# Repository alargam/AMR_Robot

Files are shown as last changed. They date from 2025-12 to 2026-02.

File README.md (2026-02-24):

# 🤖 Autonomous Mobile Robot (AMR)
### ROS 2 Jazzy | Real-Time Perception | Embedded Control | Edge AI

An end-to-end **Autonomous Mobile Robot (AMR)** platform developed as a Mechatronics Engineering Graduation Project (2026).

This project integrates real-time perception, sensor fusion, embedded motor control, SLAM, and autonomous navigation into a complete robotic system designed using ROS 2 Jazzy best practices.

---

You can visit the official project website for more details: [https://delivero.site/](https://delivero.site/)

---

## 🎥 Demonstration

Mapping Demo: [link](https://www.youtube.com/shorts/1S7ldnf2kuI)

Autonomous Navigation Demo: [link](https://youtu.be/pdu4tVg_QxQ?si=NQ7DHxntDtQeoHpF)

Real-World Robot Demo [link](https://www.youtube.com/shorts/1S7ldnf2kuI)

---

# 🏗️ System Architecture

| Sensor / Input | Processing Node / Algorithm | Output Topic / Interface |
|---|---|---|
| Camera | Perception Node (TensorRT) | `/detections` |
| LiDAR | SLAM Toolbox | `/map` |
| Encoders + IMU | EKF (Extended Kalman Filter) | `/odom` |
| Navigation (Nav2) | Path Planner / Controller | `/cmd_vel` → micro-ROS (ESP32) → Motor Driver → Wheels |

The system is modular and scalable, separating hardware drivers, robot description, and system integration layers.

---

# 🧠 Real-Time Perception Pipeline

The robot integrates an optimized deep learning perception system:

- Model: YOLOv11n
- Framework: PyTorch → ONNX → TensorRT
- Precision: INT8, FP32
- Deployment: Custom ROS 2 inference node
- Output Topic: `/detections`

## 📊 Inference Performance (Edge Deployment)

| Mode  | FPS | Latency | Hardware |
|---|-----|---|---|
| FP32  | 4–6  FPS  | 160–250 ms | Raspberry Pi 5 |
| INT8  | 12–18 FPS | 55–85 ms | Raspberry Pi 5 |

Measured on CPU-only deployment, actual FPS may improve with GPU/Edge Accelerator

---

# 🧭 Localization & Sensor Fusion

Localization is implemented using `robot_localization` (EKF):

- IMU + Wheel Encoder fusion
- REP-105 compliant TF tree:

map → odom → base_link

## 📊 EKF & Control Performance

- EKF update rate: <XX Hz>
- Control loop frequency: <XX Hz>
- Odometry drift: <XX% over XX meters>
- Maximum linear velocity: <XX m/s>
- Maximum angular velocity: <XX rad/s>

---

# 🛰️ Navigation Stack

- SLAM Toolbox for real-time mapping
- Navigation2 (Nav2) for path planning
- Dynamic obstacle avoidance
- Waypoint navigation support

## Autonomous Capabilities

- ✅ Mapping
- ✅ Localization
- ✅ Path planning
- ✅ Obstacle avoidance

---

# 🔌 Embedded & Low-Level Control

Low-level control handled via:

- ESP32 running micro-ROS
- Serial communication (`/dev/esp32`)
- Encoder feedback at <XX Hz>
- Closed-loop motor control

## Communication Metrics

- micro-ROS latency: <XX ms average>
- Serial baud rate: <XXXXXX>
- Motor response delay: <XX ms>

---

# 🛠️ Hardware Stack

| Component | Model |
|---|---|
| LiDAR | LD06 |
| Camera | Orbbec Astra Pro |
| MCU | ESP32 S3 |
| Main Compute | Raspberry Pi 5 |
| Motor Driver | BTS7960 |
| Battery | 24V |

---

# 📊 System Resource Usage

Measured during full operation:

| Metric | Value |
|---|---|
| CPU Usage | 70–85% average |
| RAM Usage | 1.5–2.0 GB|
| Power Consumption | 12–15 W |
| Runtime per charge | 10–15 hours |

---

# 📂 Repository Structure

```text
AMR_Robot/
├── src/
│   ├── hardware/
│   │   ├── ldlidar_ros2/
│   │   ├── micro-ROS-Agent/
│   │   ├── micro_ros_msgs/
│   │   ├── ros2_astra_camera/
│   │   └── my_robot_description/
│   │       ├── config/
│   │       ├── meshs/
│   │       └── urdf/
│   └── robot_bringup/
│       ├── ESP32_code/
│       ├── config/
│       ├── launch/
│       ├── maps/
│       ├── HARDWARE_SPECIFICATIONS.md
│       └── package.xml
├── .gitignore
└── README.md
```

The architecture follows a clear separation of concerns to ensure maintainability and scalability.

---

# 🚀 Build & Deployment

## 1️⃣ Setup Device Rules

```bash
bash robot_bringup/scripts/setup_rules.sh
```

## 2️⃣ Build Workspace
```bash
colcon build --symlink-install
source install/setup.bash
```

3️⃣ Launch Robot
```bash
start_robot
```

## 🧠 Engineering Highlights

```
This project demonstrates:

End-to-end robotics system integration

Real-time AI deployment on edge hardware

ROS 2 modular architecture design

Embedded systems integration via micro-ROS

Performance optimization under hardware constraints

Production-oriented robotics engineering practices
```
---

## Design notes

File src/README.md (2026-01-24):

🤖 AMR Autonomous Mobile Robot (AMR) – ROS 2 Jazzy
This repository contains the complete hardware bringup, system integration, and software architecture for an Autonomous Mobile Robot (AMR) developed as a Mechatronics Engineering Graduation Project (2026).

The project is carefully structured to separate hardware drivers, robot description, and system logic, following professional ROS 2 Jazzy best practices.

🏗️ Project Architecture Overview
The source code (src) is organized to ensure scalability, maintainability, and clear responsibility separation:

hardware/ Contains all low-level hardware drivers and communication bridges.

my_robot_description/ Defines the physical structure of the robot using URDF, meshes, and TF relationships.

robot_bringup/ The system integration layer ("robot brain") that unifies sensors, localization, and launch logic.

🚀 Quick Start Aliases
To simplify field operation and debugging, the following aliases are configured in .bashrc:

1️⃣ Launch Commands
Alias	Description	Launch File
start_robot	Launch the complete robot system	robot_bringup/full_robot.launch.py
start_lidar	Start LD06 LiDAR driver	ldlidar_ros2/ld06.launch.py
start_camera	Start Orbbec Astra Pro camera	astra_camera/astra_pro.launch.xml
start_esp	Start micro-ROS agent (ESP32)	Serial via /dev/esp32
2️⃣ Verification Commands
check_topics – Lists all active ROS 2 topics
check_odom – Monitors filtered odometry output from EKF
🧭 Sensor Fusion & Localization
The robot uses the robot_localization package to fuse wheel encoder odometry and IMU data.

Key Features
Extended Kalman Filter (EKF) for accurate state estimation
Drift reduction and smooth pose output
REP-105 compliant TF tree:
map → odom → base_link
Compatible with ROS 2 Jazzy using the rolling-devel branch
📂 Repository Structure
AMR_Robot/
├── src/
│   ├── hardware/               # Drivers & Communication
│   │   ├── ldlidar_ros2/        # LD06 LiDAR Driver
│   │   ├── micro-ROS-Agent/     # ESP32 micro-ROS Bridge
│   │   └── ros2_astra_camera/   # Orbbec Astra Pro Driver
│   ├── my_robot_description/   # Robot Physical Model
│   │   ├── urdf/               # URDF & TF Definitions
│   │   └── mesh/               # 3D Meshes
│   └── robot_bringup/          # System Integration
│       ├── config/             # EKF & Navigation Parameters
│       ├── scripts/            # Utility & Odometry Scripts
│       └── launch/             # Master Launch Files
🛠️ Build & Installation
1️⃣ Device Rules Setup
Ensure persistent device naming by running:

bash robot_bringup/scripts/setup_rules.sh
2️⃣ Build the Workspace
colcon build --symlink-install
source install/setup.bash
3️⃣ Start the Robot
start_robot
🛰️ Hardware Components
🔴 LD06 2D LiDAR – 360° planar environment scanning
📷 Orbbec Astra Pro – RGB + Depth perception
🟢 ESP32 (micro-ROS) – Motor control, encoders, and IMU bridge
🍓 Raspberry Pi 5 – Main ROS 2 computation unit
🔗 References & Official Packages
🛠️ Middleware & Communication
micro-ROS Agent https://github.com/micro-ROS/micro-ROS-Agent

micro-ROS Arduino Client https://github.com/micro-ROS/micro_ros_arduino

🛰️ Sensors & Perception
LD06 LiDAR Driver https://github.com/ldrobotSensorTeam/ldlidar_ros2

Orbbec Astra Camera Driver https://github.com/orbbec/ros2_astra_camera

🧭 Localization & Navigation
Robot Localization (EKF) https://github.com/cra-ros-pkg/robot_localization

SLAM Toolbox https://github.com/SteveMacenski/slam_toolbox

Navigation2 (Nav2) https://github.com/ros-navigation/navigation2

🔮 Future Work
Full Navigation2 (Nav2) integration
Autonomous waypoint navigation
Fault detection & sensor redundancy
Real-time monitoring dashboard
Built with ❤️ for ROS 2 Jazzy and Autonomous Robotics AMR Graduation Project – Mechatronics Engineering (2026)

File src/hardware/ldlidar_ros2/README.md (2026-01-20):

# Instructions

## step 0: get LiDAR ROS2 Package
```bash
cd ~

mkdir -p ldlidar_ros2_ws/src

cd ldlidar_ros2_ws/src

git clone  https://github.com/ldrobotSensorTeam/ldlidar_ros2.git

git submodule update --init --recursive
```
## step 1: system setup
- Connect the LiDAR to your system motherboard via an onboard serial port or usB-to-serial module (for example, CP2102 module).

- Set the -x permission for the serial port device mounted by the radar in the system (for example, /dev/ttyUSB0)

  - In actual use, the LiDAR can be set according to the actual mounted status of your system, you can use 'ls -l /dev' command to view.

``` bash
cd ~/ldlidar_ros2_ws

sudo chmod 777 /dev/ttyUSB0
```
- Modify the `port_name` value in the Lanuch file corresponding to the radar product model under `launch/`, using `ld14.launch.py` as an example, as shown below.

```py
#!/usr/bin/env python3
from launch import LaunchDescription
from launch_ros.actions import Node

'''
Parameter Description:
---
- Set laser scan directon: 
  1. Set counterclockwise, example: {'laser_scan_dir': True}
  2. Set clockwise,        example: {'laser_scan_dir': False}
- Angle crop setting, Mask data within the set angle range:
  1. Enable angle crop fuction:
    1.1. enable angle crop,  example: {'enable_angle_crop_func': True}
    1.2. disable angle crop, example: {'enable_angle_crop_func': False}
  2. Angle cropping interval setting:
  - The distance and intensity data within the set angle range will be set to 0.
  - angle >= 'angle_crop_min' and angle <= 'angle_crop_max' which is [angle_crop_min, angle_crop_max], unit is degress.
    example:
      {'angle_crop_min': 135.0}
      {'angle_crop_max': 225.0}
      which is [135.0, 225.0], angle unit is degress.
'''

def generate_launch_description():
  # LDROBOT LiDAR publisher node
  ldlidar_node = Node(
      package='ldlidar_ros2',
      executable='ldlidar_ros2_node',
      name='ldlidar_publisher_ld14',
      output='screen',
      parameters=[
        {'product_name': 'LDLiDAR_LD14'},
        {'laser_scan_topic_name': 'scan'},
        {'point_cloud_2d_topic_name': 'pointcloud2d'},
        {'frame_id': 'base_laser'},
        {'port_name': '/dev/ttyAMA0'},
        {'serial_baudrate' : 115200},
        {'laser_scan_dir': True},
        {'enable_angle_crop_func': False},
        {'angle_crop_min': 135.0},
        {'angle_crop_max': 225.0}
      ]
  )

  # base_link to base_laser tf node
  base_link_to_laser_tf_node = Node(
    package='tf2_ros',
    executable='static_transform_publisher',
    name='base_link_to_base_laser_ld14',
    arguments=['0','0','0.18','0','0','0','base_link','base_laser']
  )

  # Define LaunchDescription variable
  ld = LaunchDescription()

  ld.add_action(ldlidar_node)
  ld.add_action(base_link_to_laser_tf_node)

  return ld
```

## step 2: build

Run the following command.

```bash
cd ~/ldlidar_ros2_ws

colcon build
```
## step 3: run

### step3.1: package environment variable settings

- After the compilation is completed, you need to add the relevant files generated by the compilation to the environment variables, so that the ROS environment can recognize them. The execution command is as follows. This command is to temporarily add environment variables to the terminal, which means that if you reopen a new terminal, you also need to re-execute it. The following command.
  
  ```bash
  cd ~/ldlidar_ros2_ws
  
  source install/local_setup.bash
  ```
  
- In order to never need to execute the above command to add environment variables after reopening the terminal, you can do the following.

  ```bash
  echo "source ~/ldlidar_ros2_ws/install/local_setup.bash" >> ~/.bashrc
  
  source ~/.bashrc
  ```
### step3.2: start LiDAR node

- The product is LDROBOT LiDAR LD14
  - start ld14 lidar node:
  ``` bash
  ros2 launch ldlidar_ros2 ld14.launch.py
  ```
  - start ld14 lidar node and show on the Rviz2:
  ``` bash
  ros2 launch ldlidar_ros2 viewer_ld14.launch.py
  ```

- The product is LDROBOT LiDAR LD14P
  - start ld14p lidar node:
  ``` bash
  ros2 launch ldlidar_ros2 ld14p.launch.py
  ```
  - start ld14p lidar node and show on the Rviz2:
  ``` bash
  ros2 launch ldlidar_ros2 viewer_ld14p.launch.py
  ```

- The product is LDROBOT LiDAR LD06
  - start ld06 lidar node:
  ``` bash
  ros2 launch ldlidar_ros2 ld06.launch.py
  ```
  - start ld06 lidar node and show on the Rviz2:
  ``` bash
  ros2 launch ldlidar_ros2 viewer_ld06.launch.py
  ```

- The product is LDROBOT LiDAR LD19
  - start ld19 lidar node:
  ``` bash
  ros2 launch ldlidar_ros2 ld19.launch.py
  ```
  - start ld19 lidar node and show on the Rviz2:
  ``` bash
  ros2 launch ldlidar_ros2 viewer_ld19.launch.py
  ```

## step 4: Data visualization

> The code supports ubuntu 20.04 ros2 foxy version and above, using rviz2 visualization.

- new a terminal (Ctrl + Alt + T) and use Rviz2 tool(run command: `rviz2`) ,open the `ldlidar.rviz` file below the rviz2 folder of the readme file directory
```bash
rviz2
```

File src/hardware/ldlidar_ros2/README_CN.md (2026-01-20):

# 操作指南

## 0. 获取激光雷达的ROS2功能包
```bash
cd ~

mkdir -p ldlidar_ros2_ws/src

cd ldlidar_ros2_ws/src

git clone  https://github.com/ldrobotSensorTeam/ldlidar_ros2.git

git submodule update --init --recursive
```
## 1. 系统设置
- 第一步，通过板载串口或者USB转串口模块(例如,cp2102模块)的方式使雷达连接到你的系统主板.
- 第二步，设置雷达在系统中挂载的串口设备-x权限(以/dev/ttyUSB0为例)
	- 实际使用时，根据雷达在你的系统中的实际挂载情况来设置，可以使用`ls -l /dev`命令查看.

``` bash
cd ~/ldlidar_ros2_ws

sudo chmod 777 /dev/ttyUSB0
```
- 第三步，修改`launch/`目录下雷达产品型号对应的lanuch文件中的`port_name`值，以ld14.launch.py为例，如下所示.

```py
#!/usr/bin/env python3
from launch import LaunchDescription
from launch_ros.actions import Node

'''
Parameter Description:
---
- Set laser scan directon: 
  1. Set counterclockwise, example: {'laser_scan_dir': True}
  2. Set clockwise,        example: {'laser_scan_dir': False}
- Angle crop setting, Mask data within the set angle range:
  1. Enable angle crop fuction:
    1.1. enable angle crop,  example: {'enable_angle_crop_func': True}
    1.2. disable angle crop, example: {'enable_angle_crop_func': False}
  2. Angle cropping interval setting:
  - The distance and intensity data within the set angle range will be set to 0.
  - angle >= 'angle_crop_min' and angle <= 'angle_crop_max' which is [angle_crop_min, angle_crop_max], unit is degress.
    example:
      {'angle_crop_min': 135.0}
      {'angle_crop_max': 225.0}
      which is [135.0, 225.0], angle unit is degress.
'''

def generate_launch_description():
  # LDROBOT LiDAR publisher node
  ldlidar_node = Node(
      package='ldlidar_ros2',
      executable='ldlidar_ros2_node',
      name='ldlidar_publisher_ld14',
      output='screen',
      parameters=[
        {'product_name': 'LDLiDAR_LD14'},
        {'laser_scan_topic_name': 'scan'},
        {'point_cloud_2d_topic_name': 'pointcloud2d'},
        {'frame_id': 'base_laser'},
        {'port_name': '/dev/ttyAMA0'},
        {'serial_baudrate' : 115200},
        {'laser_scan_dir': True},
        {'enable_angle_crop_func': False},
        {'angle_crop_min': 135.0},
        {'angle_crop_max': 225.0}
      ]
  )

  # base_link to base_laser tf node
  base_link_to_laser_tf_node = Node(
    package='tf2_ros',
    executable='static_transform_publisher',
    name='base_link_to_base_laser_ld14',
    arguments=['0','0','0.18','0','0','0','base_link','base_laser']
  )

  # Define LaunchDescription variable
  ld = LaunchDescription()

  ld.add_action(ldlidar_node)
  ld.add_action(base_link_to_laser_tf_node)

  return ld
```
## 2. 编译方法

使用colcon编译.

```bash
cd ~/ldlidar_ros2_ws

colcon build
```
## 3. 运行方法
### 3.1. 设置功能包环境变量

- 编译完成后需要将编译生成的相关文件加入环境变量，便于 ROS 环境可以识别， 执行命令如下所示， 该命令是临时给终端加入环境变量，意味着您如果重新打开新的终端，也需要重新执行如下命令.

  ```bash
  cd ~/ldlidar_ros2_ws
  
  source install/local_setup.bash
  ```
- 为了重新打开终端后，永久不用执行上述添加环境变量的命令，可以进行如下操作.

  ```bash
  echo "source ~/ldlidar_ros2_ws/install/local_setup.bash" >> ~/.bashrc
  
  source ~/.bashrc
  ```
### 3.2. 启动激光雷达节点

- 产品型号为 LDROBOT LiDAR LD14
  - 启动ld14 lidar node:
  ``` bash
  ros2 launch ldlidar_ros2 ld14.launch.py
  ```
  - 启动ld14 lidar node并显示激光数据在Rviz2上:
  ``` bash
  ros2 launch ldlidar_ros2 viewer_ld14.launch.py
  ```

- 产品型号为 LDROBOT LiDAR LD14P
  - 启动ld14p lidar node:
  ``` bash
  ros2 launch ldlidar_ros2 ld14p.launch.py
  ```
  - 启动ld14p lidar node并显示激光数据在Rviz2上:
  ``` bash
  ros2 launch ldlidar_ros2 viewer_ld14p.launch.py
  ```

- 产品型号为 LDROBOT LiDAR LD06
  - 启动ld06 lidar node:
  ``` bash
  ros2 launch ldlidar_ros2 ld06.launch.py
  ```
  - 启动ld14 lidar node并显示激光数据在Rviz2上:
  ``` bash
  ros2 launch ldlidar_ros2 viewer_ld06.launch.py
  ```

- 产品型号为 LDROBOT LiDAR LD19
  - 启动ld19 lidar node:
  ``` bash
  ros2 launch ldlidar_ros2 ld19.launch.py
  ```
  - 启动ld19 lidar node并显示激光数据在Rviz2上:
  ``` bash
  ros2 launch ldlidar_ros2 viewer_ld19.launch.py
  ```
##   4. 可视化

> 代码支持ubuntu20.04 ROS2 foxy版本及以上测试，使用rviz2可视化。
- 新打开一个终端 (Ctrl + Alt + T),运行命令:`rviz2`,并通过Rviz2工具打开readme文件所在目录的rviz2文件夹下面的ldlidar.rviz文件
```bash
rviz2
```

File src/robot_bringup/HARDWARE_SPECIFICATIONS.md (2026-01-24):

# 🛠️ Falcon AMR - Complete Hardware Specifications

This document provides a technical overview of the Falcon AMR hardware architecture, electrical connections, and physical configuration.

---

## 🏗️ 1. Mechanical Structure
The robot is based on a 4-wheel drive (4WD) chassis designed for indoor autonomous navigation.

| Feature | Specification |
| :--- | :--- |
| **Chassis Type** | 4-Wheel Differential Drive |
| **Ground Clearance** | `0.02 m` (2 cm) - Ground to bottom of chassis |
| **Wheel Diameter** | `0.16 m` (16 cm) |
| **Wheel Radius** | `0.07 m` (7 cm) |
| **Wheel Track (Separation)** | `0.44 m` (44 cm) |
| **Total Weight** | Approx. `9.0 kg` |

---

## ⚡ 2. Electrical & Control System
The system uses a hierarchical control strategy: **Raspberry Pi 5** for high-level processing and **ESP32** for low-level motor control.

### **Core Components**
* **High-Level Controller:** Raspberry Pi 5 (8GB RAM) running ROS 2 Jazzy.
* **Low-Level Controller:** ESP32 (connected via Micro-ROS).
* **Power Source:** [Insert Battery Type, e.g., 12V Li-Po]
* **Motor Drivers:** [Insert Driver Type, e.g., BTS7960 or L298N]

---

## 📡 3. Sensors & Connectivity
The robot is equipped with a suite of sensors for environment perception.

| Sensor | Purpose | Connection Type | Baudrate / Port |
| :--- | :--- | :--- | :--- |
| **LiDAR LD06** | 2D SLAM & Obstacle Avoidance | Serial Over USB | `230400` / `/dev/ldlidar` |
| **ESP32 (Odom)** | Encoder Data & Motor PWM | Micro-ROS (Serial) | `115200` / `/dev/esp32` |
| **Astra Pro Max** | 3D Depth & RGB Vision | USB 3.0 | N/A |
| **GPS Module** | Outdoor Global Positioning | Serial | N/A |

---

## 📏 4. Sensor Mounting Heights (TF Offsets)
All heights are measured from the **Ground Surface** to the center of the sensor's lens/scanning plane.

* **LiDAR Scanning Plane:** `0.38 m` (38 cm)
* **Camera Optical Center:** `0.22 m` (22 cm)
* **GPS Antenna:** `0.31 m` (31 cm)

---

## 📝 5. Hardware Implementation Checklist
- [x] **Persistent USB Rules:** Created udev rules for `/dev/ldlidar` and `/dev/esp32` to prevent port swapping.
- [x] **LiDAR Configuration:** Serial baudrate confirmed at `230400`.
- [x] **Micro-ROS Connectivity:** Agent baudrate confirmed at `115200`.
- [x] **URDF Accuracy:** Updated `base_joint` with `0.02m` ground clearance and verified sensor Z-offsets.
- [ ] **Motor Polarity:** Verified that positive `cmd_vel` moves the robot forward.
- [ ] **Encoder Phase:** Verified that forward movement increases the tick count in `/odom`.

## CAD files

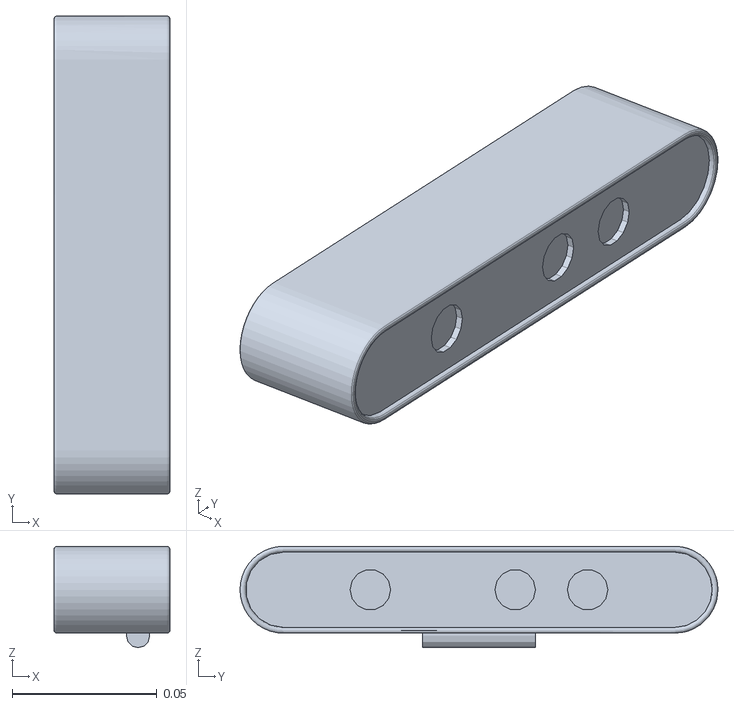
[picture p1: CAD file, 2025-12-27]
src/my_robot_description/meshs/camera_link.STL
0.04 x 0.165 x 0.035

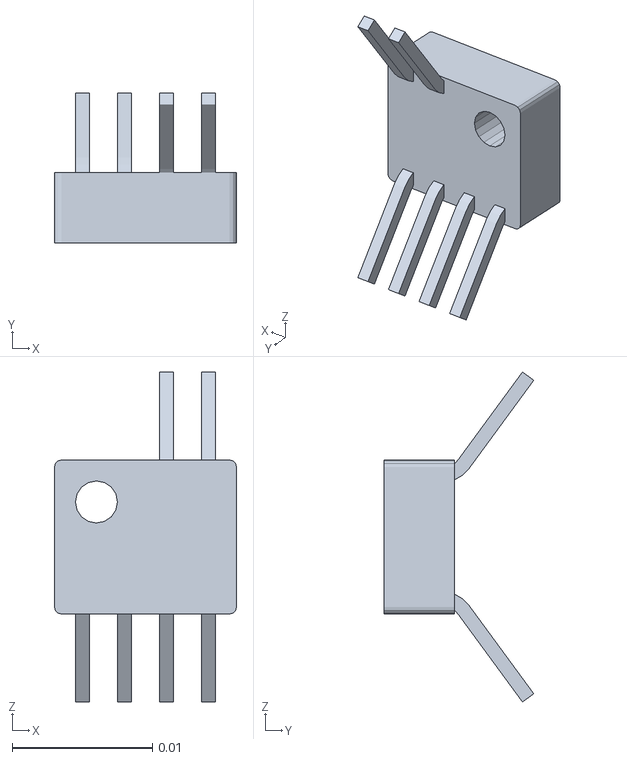
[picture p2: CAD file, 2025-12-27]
src/my_robot_description/meshs/Tof_FR_link.STL
0.013 x 0.0107 x 0.0236

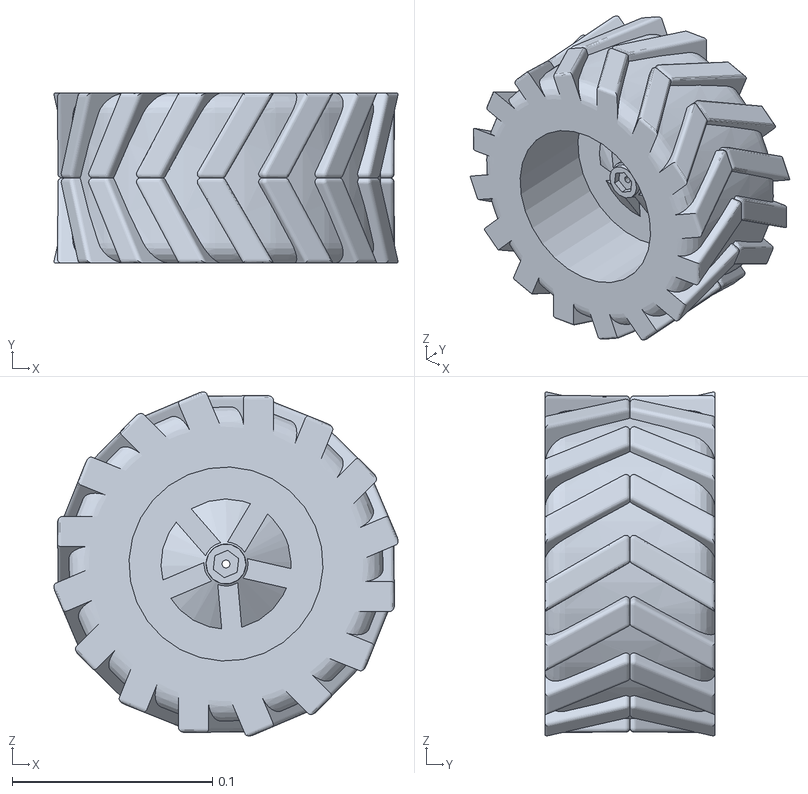
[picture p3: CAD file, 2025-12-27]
src/my_robot_description/meshs/back_left_wheel_link.STL
0.172 x 0.085 x 0.172

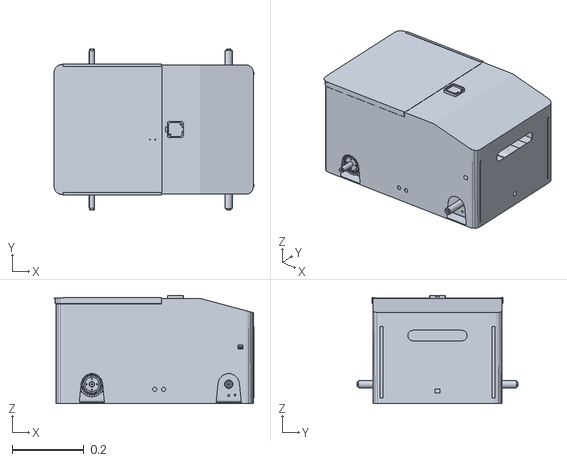
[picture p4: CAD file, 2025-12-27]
src/my_robot_description/meshs/base_link.STL
0.558 x 0.45 x 0.302

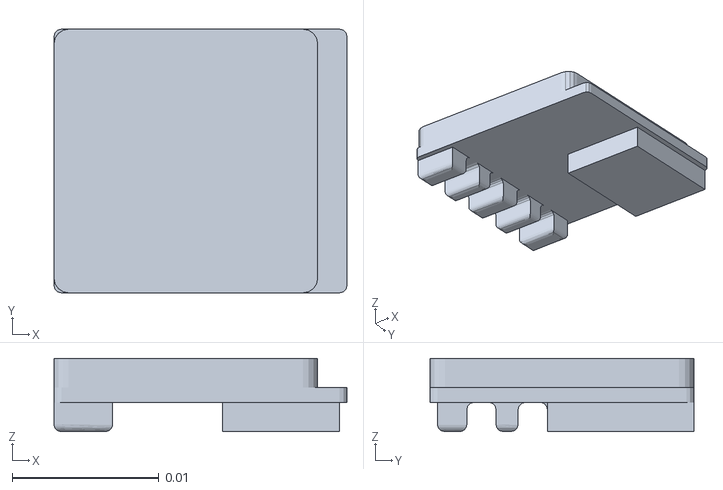
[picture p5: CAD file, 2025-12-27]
src/my_robot_description/meshs/gps_link.STL
0.02 x 0.018 x 0.005

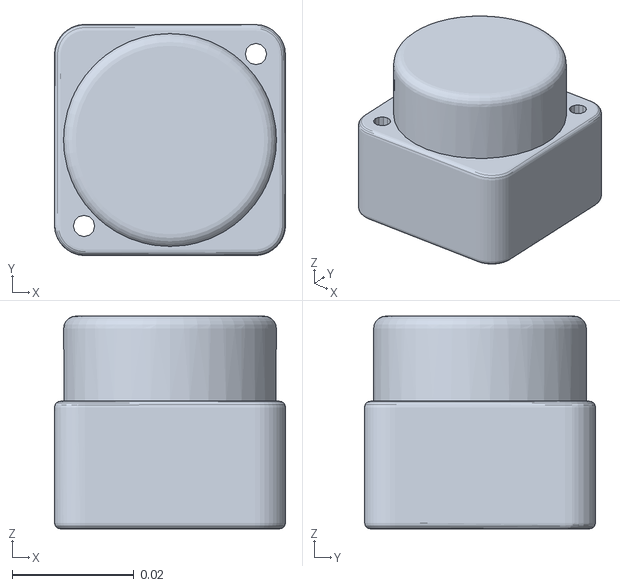
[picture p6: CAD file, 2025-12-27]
src/my_robot_description/meshs/lidar_link.STL
0.038 x 0.038 x 0.035

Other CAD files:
src/my_robot_description/meshs/Tof_BL_link.STL
src/my_robot_description/meshs/front_left_wheel_link.STL
src/my_robot_description/meshs/Tof_BR_link.STL
src/my_robot_description/meshs/Tof_FL_link.STL
src/my_robot_description/meshs/Tof_F_Link.STL
src/my_robot_description/meshs/front_right_wheel_link.STL
src/my_robot_description/meshs/back_right_wheel_link.STL

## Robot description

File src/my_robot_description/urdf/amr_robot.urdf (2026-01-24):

<robot name="my_amr_robot">
  
  <link name="base_footprint" />
  
  <joint name="base_joint" type="fixed">
        <parent link="base_footprint" />
        <child link="base_link" />
        <origin xyz="0 0 0.02" rpy="0 0 0"/>
  </joint>

  <link name="base_link">
    <inertial>
      <origin xyz="0 0 0" rpy="0 0 0" />
      <mass value="9" />
      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
    </inertial>
    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
  </link>

  <link name="front_right_wheel_link">
    <inertial>
      <origin xyz="0 0 0" rpy="0 0 0" />
      <mass value="1.25" />
      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
    </inertial>
    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
  </link>
  <joint name="front_right_wheel_joint" type="continuous">
    <origin xyz="0.18772 -0.218 0.0005" rpy="0 0 0" />
    <parent link="base_link" />
    <child link="front_right_wheel_link" />
    <axis xyz="0 1 0" />
    <limit effort="35" velocity="50" />
  </joint>

  <link name="front_left_wheel_link">
    <inertial>
      <origin xyz="0 0 0" rpy="0 0 0" />
      <mass value="1.25" />
      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
    </inertial>
    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
  </link>
  <joint name="front_left_wheel_joint" type="continuous">
    <origin xyz="0.18772 0.225 0.0005" rpy="0 0 0" />
    <parent link="base_link" />
    <child link="front_left_wheel_link" />
    <axis xyz="0 1 0" />
    <limit effort="35" velocity="50" />
  </joint>

  <link name="back_left_wheel_link">
    <inertial>
      <origin xyz="0 0 0" rpy="0 0 0" />
      <mass value="1.25" />
      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
    </inertial>
    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
  </link>
  <joint name="back_left_wheel_joint" type="continuous">
    <origin xyz="-0.19428 0.225 0.0005" rpy="0 0 0" />
    <parent link="base_link" />
    <child link="back_left_wheel_link" />
    <axis xyz="0 1 0" />
    <limit effort="35" velocity="50" />
  </joint>

  <link name="back_right_wheel_link">
    <inertial>
      <origin xyz="0 0 0" rpy="0 0 0" />
      <mass value="1.25" />
      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
    </inertial>
    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
  </link>
  <joint name="back_right_wheel_joint" type="continuous">
    <origin xyz="-0.19428 -0.218 0.0005" rpy="0 0 0" />
    <parent link="base_link" />
    <child link="back_right_wheel_link" />
    <axis xyz="0 1 0" />
    <limit effort="35" velocity="50" />
  </joint>

  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

  <link name="lidar_link">
    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
  </link>
  <joint name="lidar_joint" type="fixed">
    <origin xyz="0.03872 0.00389 0.36" rpy="0 0 0" />
    <parent link="base_link" />
    <child link="lidar_link" />
  </joint>

  <link name="camera_link">
    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
  </link>
  <joint name="camera_joint" type="fixed">
    <origin xyz="0.25622 0.01 0.20" rpy="0 0 0" />
    <parent link="base_link" />
    <child link="camera_link" />
  </joint>

  <link name="gps_link">
    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
  </link>
  <joint name="gps_joint" type="fixed">
    <origin xyz="0.039 0.039 0.31" rpy="0 0 0" />
    <parent link="base_link" />
    <child link="gps_link" />
  </joint>

  <link name="Tof_F_Link">
    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
  </link>
  <joint name="Tof_F_joint" type="fixed">
    <origin xyz="0.25622 0.0018543 0.10" rpy="0 0 0" />
    <parent link="base_link" />
    <child link="Tof_F_Link" />
  </joint>

  <link name="Tof_FL_link">
    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
  </link>
  <joint name="Tof_FL_joint" type="fixed">
    <origin xyz="0.22272 0.18435 0.16" rpy="0 0 0" />
    <parent link="base_link" />
    <child link="Tof_FL_link" />
  </joint>

  <link name="Tof_FR_link">
    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
  </link>
  <joint name="Tof_FR_joint" type="fixed">
    <origin xyz="0.21875 -0.17665 0.16" rpy="0 0 0" />
    <parent link="base_link" />
    <child link="Tof_FR_link" />
  </joint>

  <link name="Tof_BL_link">
    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
  </link>
  <joint name="Tof_BL_joint" type="fixed">
    <origin xyz="-0.19428 0.21469 0.10" rpy="0 0 0" />
    <parent link="base_link" />
    <child link="Tof_BL_link" />
  </joint>

  <link name="Tof_BR_link">
    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
  </link>
  <joint name="Tof_BR_joint" type="fixed">
    <origin xyz="-0.29478 -0.12406 0.10" rpy="0 0 0" />
    <parent link="base_link" />
    <child link="Tof_BR_link" />
  </joint>

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

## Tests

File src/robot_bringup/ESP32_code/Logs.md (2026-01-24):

# 🛠️ Falcon AMR – Debugging & Solutions Log

This document records the critical hardware and software issues encountered during the development of **Falcon AMR** and the precise solutions applied to resolve them.

---

## 1. LiDAR Node Crash (Invalid Topic Name)

### 🚨 The Problem

The LiDAR node (`ldlidar_ros2_node`) would start, connect to the serial port successfully, and then immediately crash with the error:

```
Invalid topic name: topic name must not be empty string
```

### ✅ The Solution

The launch file was passing a parameter named `topic_name`, but the LD06 driver expects `laser_scan_topic_name`.

**Fix:** Updated `hardware.launch.py` to use the correct parameter key:

```python
parameters=[{
    'laser_scan_topic_name': 'scan',
    'point_cloud_2d_topic_name': 'pointcloud',
}]
```

---

## 2. Odometry Drift (Incorrect Wheel Diameter)

### 🚨 The Problem

The robot was reporting incorrect distances in `/odom`. Moving the robot 1 meter physically resulted in a different distance in RViz.

### ✅ The Solution

The URDF and Gazebo plugins were configured with a wheel diameter of **0.16 m** (radius 0.08 m), while the physical measurement confirmed the wheels are **0.14 m**.

**Fix:**

1. Updated URDF collision radius to **0.07 m**
2. Updated `nav2_params.yaml` and Gazebo plugin `wheel_diameter` to **0.14 m**

---

## 3. TF Tree Disconnect (base_link vs base_footprint)

### 🚨 The Problem

Nav2 and SLAM Toolbox were reporting `LookupTransform` errors. The robot model in RViz appeared to jump or was not connected correctly to the map.

### ✅ The Solution

The EKF (Robot Localization) was publishing `odom → base_link`, while Nav2 and SLAM were expecting `base_footprint`.

**Fix:** Unified the entire system to use `base_link` as the primary robot frame in:

* `ekf.yaml`
* `nav2_params.yaml`
* `slam_toolbox.yaml`

**Final TF Chain:**

```
map → odom → base_link → sensors
```

---

## 4. ESP32 Time Synchronization (TF_OLD_DATA)

### 🚨 The Problem

ROS 2 rejected messages from the ESP32 with:

```
Message contains older data than latest transform
```

This occurred because the ESP32 clock (`millis()`) was not synchronized with the Raspberry Pi Unix time.

### ✅ The Solution

Implemented **micro-ROS time synchronization** on the ESP32.

**Fix:**

* Used `rmw_uros_sync_session(1000)` in `setup()`
* Timestamped messages using `rmw_uros_epoch_millis()`

```cpp
odom_msg.header.stamp.sec = rmw_uros_epoch_millis() / 1000;
```

---

## 5. Serial Port Permission Denied

### 🚨 The Problem

ROS nodes could not open `/dev/ttyUSB0` or `/dev/ttyACM0` without `sudo`, and device names would randomly swap (e.g., LiDAR becoming `ttyUSB1`).

### ✅ The Solution

Created **persistent udev rules** to lock device names and grant permanent permissions.

**Fix:** Created `/etc/udev/rules.d/99-robot-serial.rules`

```bash
KERNEL=="ttyUSB*", ATTRS{idVendor}=="10c4", SYMLINK+="ldlidar", MODE="0666"
KERNEL=="ttyACM*", ATTRS{idVendor}=="303a", SYMLINK+="esp32", MODE="0666"
```

---

## 6. micro-ROS Compilation Errors (Undeclared Objects)

### 🚨 The Problem

Compilation failed with:

```
'odom_msg' was not declared in this scope
```

### ✅ The Solution

In C++, variables must be declared **before** the functions that use them.

**Fix:** Reordered the `.ino` file so all micro-ROS objects (`rcl_publisher_t`, messages, etc.) are declared at the top of the file, before `publishOdometry()`.

---

## 7. EKF NaN / Inf State Detection

### 🚨 The Problem

The EKF node crashed with:

```
Critical Error: NaNs were detected in the output state
```

### ✅ The Solution

The ESP32 was sending invalid `dt` values (0 or NaN) during the first loop iteration, causing division by zero in velocity calculations.

**Fix:** Added a safety check in the ESP32 code:

```cpp
if (dt <= 0.0 || isnan(dt)) return; // Skip invalid calculation
```

---

## 8. LiDAR Static Transform Jitter

### 🚨 The Problem

The LiDAR scan in RViz was shaking or misaligned relative to the robot body.

### ✅ The Solution

There was a conflict between:

* `static_transform_publisher` in the launch file
* The LiDAR joint defined in the URDF

**Fix:** Removed the manual static transform from the launch file and relied exclusively on `robot_state_publisher` to publish the sensor transform from the URDF.

---

## 📌 Next Step

Would you like help pushing this README to your GitHub repository (including commit and push commands)?

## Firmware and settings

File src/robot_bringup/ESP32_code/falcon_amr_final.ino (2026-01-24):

#include <Arduino.h>
#include <micro_ros_arduino.h>
#include <rcl/rcl.h>
#include <rclc/rclc.h>
#include <rclc/executor.h>
#include <nav_msgs/msg/odometry.h>
#include <std_msgs/msg/int32.h>
#include <geometry_msgs/msg/twist.h>
#include <math.h>

/* ================= 1. PIN DEFINITIONS (BTS7960) ================= */
#define L_EN1      6
#define L_EN2      7
#define L_RPWM     4
#define L_LPWM     5
#define ENC_L_PIN  2

#define R_EN1      35
#define R_EN2      48
#define R_RPWM     36
#define R_LPWM     37
#define ENC_R_PIN  1

/* ================= 2. ROBOT GEOMETRY & PWM CONFIG ================= */
#define WHEEL_RADIUS   0.09
#define WHEEL_BASE     0.44
#define TICKS_PER_REV  20.0
#define PWM_FREQ       20000
#define PWM_RES        8
#define MAX_SPEED      0.5  // m/s linear speed

/* ================= 3. VARIABLES ================= */
volatile long countL = 0, countR = 0;
volatile int8_t dirSignL = 0, dirSignR = 0;
long odom_prevL = 0, odom_prevR = 0; 
double x = 0.0, y = 0.0, theta = 0.0;

static char odom_frame[] = "odom";
static char base_frame[] = "base_footprint";

rcl_publisher_t odom_pub;
rcl_publisher_t encL_pub;
rcl_publisher_t encR_pub;
rcl_subscription_t cmd_sub;
nav_msgs__msg__Odometry odom_msg;
std_msgs__msg__Int32 encL_msg;
std_msgs__msg__Int32 encR_msg;
geometry_msgs__msg__Twist twist_msg;
rclc_support_t support;
rcl_node_t node;
rclc_executor_t executor;
rcl_allocator_t allocator;

/* ================= 4. INTERRUPTS ================= */
void IRAM_ATTR ISR_L() { countL += dirSignL; }
void IRAM_ATTR ISR_R() { countR += dirSignR; }

/* ================= 5. MOTOR CONTROL ================= */
const int TRIM_L_F = 0;
const int TRIM_R_F = -10;
const int TRIM_L_B = -10;
const int TRIM_R_B = 0;

uint8_t targetSpeedL = 0;
uint8_t targetSpeedR = 0;
uint8_t actualSpeedL = 0;
uint8_t actualSpeedR = 0;

char actualDir  = 'X';  // X = stop, F = forward, B = backward, R = turn right, T = turn left

const int CH_L_FWD = 0;
const int CH_L_BWD = 1;
const int CH_R_FWD = 2;
const int CH_R_BWD = 3;

int motorSign(char dir, int motor) {
    switch (dir) {
        case 'F': return  1;
        case 'B': return -1;
        case 'R': return (motor == 0 ?  1 : -1);
        case 'T': return (motor == 0 ? -1 :  1);
        default:  return  0;
    }
}

void applyMotors(char dir, uint8_t spdL, uint8_t spdR) {
    int sL = motorSign(dir, 0);
    int sR = -motorSign(dir, 1);

    int cmdL = spdL;
    int cmdR = spdR;

    if (dir == 'F') { cmdL += TRIM_L_F; cmdR += TRIM_R_F; }
    else if (dir == 'B') { cmdL += TRIM_L_B; cmdR += TRIM_R_B; }

    cmdL = constrain(cmdL, 0, 255);
    cmdR = constrain(cmdR, 0, 255);

    ledcWrite(CH_L_FWD, sL > 0 ? cmdL : 0);
    ledcWrite(CH_L_BWD, sL < 0 ? cmdL : 0);
    ledcWrite(CH_R_FWD, sR > 0 ? cmdR : 0);
    ledcWrite(CH_R_BWD, sR < 0 ? cmdR : 0);
}

/* ================= 5b. Exponential Stop ================= */
float expFactor = 0.2; // smaller = slower stop
void updateRamp() {
    // exponential-like ramping
    actualSpeedL = (uint8_t)((float)actualSpeedL + (float)(targetSpeedL - actualSpeedL) * expFactor);
    actualSpeedR = (uint8_t)((float)actualSpeedR + (float)(targetSpeedR - actualSpeedR) * expFactor);

    applyMotors(actualDir, actualSpeedL, actualSpeedR);

    dirSignL = motorSign(actualDir, 0);
    dirSignR = motorSign(actualDir, 1);
}

/* ================= 6. ODOMETRY ================= */
void publishOdometry() {
    static uint32_t last_time = 0;
    uint32_t now = millis();
    float dt = (now - last_time) / 1000.0;
    if (dt <= 0 || dt > 0.5) { last_time = now; return; }
    last_time = now;

    long cL, cR;
    noInterrupts(); cL = countL; cR = countR; interrupts();
    long dL = cL - odom_prevL;
    long dR = cR - odom_prevR;
    odom_prevL = cL; odom_prevR = cR;

    double dS = (2.0 * M_PI * WHEEL_RADIUS * (dL + dR)) / (2.0 * TICKS_PER_REV);
    double dTh = (2.0 * M_PI * WHEEL_RADIUS * (dR - dL)) / (WHEEL_BASE * TICKS_PER_REV);

    x += dS * cos(theta + dTh / 2.0);
    y += dS * sin(theta + dTh / 2.0);
    theta += dTh;

    int64_t ros_now = rmw_uros_epoch_nanos();
    odom_msg.header.stamp.sec = ros_now / 1000000000ULL;
    odom_msg.header.stamp.nanosec = ros_now % 1000000000ULL;

    for(int i=0; i<36; i++) odom_msg.pose.covariance[i] = (i % 7 == 0) ? 0.01 : 0.0;

    odom_msg.header.frame_id.data = odom_frame;
    odom_msg.header.frame_id.size = strlen(odom_frame);
    odom_msg.header.frame_id.capacity = strlen(odom_frame)+1;
    odom_msg.child_frame_id.data = base_frame;
    odom_msg.child_frame_id.size = strlen(base_frame);
    odom_msg.child_frame_id.capacity = strlen(base_frame)+1;

    odom_msg.pose.pose.position.x = x;
    odom_msg.pose.pose.position.y = y;
    odom_msg.pose.pose.orientation.z = sin(theta/2.0);
    odom_msg.pose.pose.orientation.w = cos(theta/2.0);

    rcl_publish(&odom_pub, &odom_msg, NULL);

    encL_msg.data = cL;
    encR_msg.data = cR;
    rcl_publish(&encL_pub, &encL_msg, NULL);
    rcl_publish(&encR_pub, &encR_msg, NULL);
}

/* ================= 7. CMD_VEL CALLBACK ================= */
void cmd_vel_cb(const void * msgin) {
    const geometry_msgs__msg__Twist * msg = (const geometry_msgs__msg__Twist *)msgin;
    float linear  = msg->linear.x;
    float angular = msg->angular.z;

    // differential drive
    float left_vel  = linear - (angular * WHEEL_BASE / 2.0);
    float right_vel = linear + (angular * WHEEL_BASE / 2.0);

    // map velocity to PWM
    targetSpeedL = constrain((uint8_t)(fabs(left_vel) * 255.0 / MAX_SPEED), 0, 255);
    targetSpeedR = constrain((uint8_t)(fabs(right_vel) * 255.0 / MAX_SPEED), 0, 255);

    // set direction based on actual wheel velocity
    if (left_vel > 0 && right_vel > 0) actualDir = 'F';
    else if (left_vel < 0 && right_vel < 0) actualDir = 'B';
    else if (left_vel < right_vel) actualDir = 'R';
    else if (left_vel > right_vel) actualDir = 'T';
    else actualDir = 'X';
}

/* ================= 8. SETUP ================= */
void setup() {
    Serial.begin(115200);
    set_microros_transports();

    pinMode(L_EN1, OUTPUT); digitalWrite(L_EN1, HIGH);
    pinMode(L_EN2, OUTPUT); digitalWrite(L_EN2, HIGH);
    pinMode(R_EN1, OUTPUT); digitalWrite(R_EN1, HIGH);
    pinMode(R_EN2, OUTPUT); digitalWrite(R_EN2, HIGH);

    pinMode(ENC_L_PIN, INPUT_PULLUP); attachInterrupt(digitalPinToInterrupt(ENC_L_PIN), ISR_L, CHANGE);
    pinMode(ENC_R_PIN, INPUT_PULLUP); attachInterrupt(digitalPinToInterrupt(ENC_R_PIN), ISR_R, CHANGE);

    ledcSetup(CH_L_FWD, PWM_FREQ, PWM_RES);
    ledcSetup(CH_L_BWD, PWM_FREQ, PWM_RES);
    ledcSetup(CH_R_FWD, PWM_FREQ, PWM_RES);
    ledcSetup(CH_R_BWD, PWM_FREQ, PWM_RES);

    ledcAttachPin(L_RPWM, CH_L_FWD);
    ledcAttachPin(L_LPWM, CH_L_BWD);
    ledcAttachPin(R_RPWM, CH_R_FWD);
    ledcAttachPin(R_LPWM, CH_R_BWD);

    allocator = rcl_get_default_allocator();
    rclc_support_init(&support, 0, NULL, &allocator);
    rclc_node_init_default(&node, "falcon_bot_node", "", &support);

    rclc_publisher_init_default(&odom_pub, &node, ROSIDL_GET_MSG_TYPE_SUPPORT(nav_msgs, msg, Odometry), "odom/wheel");
    rclc_publisher_init_default(&encL_pub, &node, ROSIDL_GET_MSG_TYPE_SUPPORT(std_msgs, msg, Int32), "encoder/left");
    rclc_publisher_init_default(&encR_pub, &node, ROSIDL_GET_MSG_TYPE_SUPPORT(std_msgs, msg, Int32), "encoder/right");

    rclc_subscription_init_default(&cmd_sub, &node, ROSIDL_GET_MSG_TYPE_SUPPORT(geometry_msgs, msg, Twist), "cmd_vel");

    while (rmw_uros_sync_session(1000) != RMW_RET_OK) { delay(100); }

    rclc_executor_init(&executor, &support.context, 1, &allocator);
    rclc_executor_add_subscription(&executor, &cmd_sub, &twist_msg, &cmd_vel_cb, ON_NEW_DATA);
}

/* ================= 9. LOOP ================= */
void loop() {
    rclc_executor_spin_some(&executor, RCL_MS_TO_NS(10));
    updateRamp();

    static uint32_t last_odom = 0;
    if (millis() - last_odom > 50) { 
        publishOdometry();
        last_odom = millis();
    }
}

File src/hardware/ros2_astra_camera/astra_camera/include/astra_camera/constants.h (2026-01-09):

/**************************************************************************/
/* */
/* Copyright (c) 2013-2023 Orbbec 3D Technology, Inc                      */
/* */
/* PROPRIETARY RIGHTS of Orbbec 3D Technology are involved in the         */
/* subject matter of this material. All manufacturing, reproduction, use, */
/* and sales rights pertaining to this subject matter are governed by the */
/* license agreement. The recipient of this software implicitly accepts   */
/* the terms of the license.                                              */
/* */
/**************************************************************************/

#pragma once

#include <cstdint>      // Required for uint32_t
#include <string>       // Required for std::string
#include <cstdlib>      // Required for general utilities
#include <sys/types.h>  // Required for key_t

#define OB_ROS_MAJOR_VERSION 1
#define OB_ROS_MINOR_VERSION 1
#define OB_ROS_PATCH_VERSION 0

#ifndef STRINGIFY
#define STRINGIFY(arg) #arg
#endif

#ifndef VAR_ARG_STRING
#define VAR_ARG_STRING(arg) STRINGIFY(arg)
#endif

/* Return version in "X.Y.Z" format */
#define OB_ROS_VERSION_STR \
  (VAR_ARG_STRING(OB_ROS_MAJOR_VERSION.OB_ROS_MINOR_VERSION.OB_ROS_PATCH_VERSION))

namespace astra_camera {

// Default Configuration Constants
const bool ALIGN_DEPTH = false;
const bool POINTCLOUD = false;
const bool ALLOW_NO_TEXTURE_POINTS = false;
const bool SYNC_FRAMES = false;
const bool ORDERED_POINTCLOUD = false;

const bool PUBLISH_TF = true;
const double TF_PUBLISH_RATE = 0;     // 0 = Static transform
const double DIAGNOSTICS_PERIOD = 0;

const int IMAGE_WIDTH = 640;
const int IMAGE_HEIGHT = 480;
const int IMAGE_FPS = 30;

const std::string IMAGE_QOS = "SYSTEM_DEFAULT";
const std::string DEFAULT_QOS = "DEFAULT";
const std::string HID_QOS = "HID_DEFAULT";
const std::string EXTRINSICS_QOS = "EXTRINSICS_DEFAULT";

const double IMU_FPS = 0;

const bool ENABLE_DEPTH = false;
const bool ENABLE_INFRA1 = false;
const bool ENABLE_INFRA2 = false;
const bool ENABLE_COLOR = false;
const bool ENABLE_FISHEYE = false;
const bool ENABLE_IMU = false;
const bool HOLD_BACK_IMU_FOR_FRAMES = false;
const bool PUBLISH_ODOM_TF = false;

// Frame ID Constants
const std::string DEFAULT_BASE_FRAME_ID = "camera_link";
const std::string DEFAULT_ODOM_FRAME_ID = "odom_frame";
const std::string DEFAULT_DEPTH_FRAME_ID = "camera_depth_frame";
const std::string DEFAULT_INFRA1_FRAME_ID = "camera_infra1_frame";
const std::string DEFAULT_INFRA2_FRAME_ID = "camera_infra2_frame";
const std::string DEFAULT_COLOR_FRAME_ID = "camera_color_frame";
const std::string DEFAULT_FISHEYE_FRAME_ID = "camera_fisheye_frame";
const std::string DEFAULT_IMU_FRAME_ID = "camera_imu_frame";

const std::string DEFAULT_DEPTH_OPTICAL_FRAME_ID = "camera_depth_optical_frame";
const std::string DEFAULT_INFRA1_OPTICAL_FRAME_ID = "camera_infra1_optical_frame";
const std::string DEFAULT_INFRA2_OPTICAL_FRAME_ID = "camera_infra2_optical_frame";
const std::string DEFAULT_COLOR_OPTICAL_FRAME_ID = "camera_optical_color_frame";
const std::string DEFAULT_FISHEYE_OPTICAL_FRAME_ID = "camera_fisheye_optical_frame";
const std::string DEFAULT_ACCEL_OPTICAL_FRAME_ID = "camera_accel_optical_frame";
const std::string DEFAULT_GYRO_OPTICAL_FRAME_ID = "camera_gyro_optical_frame";
const std::string DEFAULT_IMU_OPTICAL_FRAME_ID = "camera_imu_optical_frame";

const std::string DEFAULT_ALIGNED_DEPTH_TO_COLOR_FRAME_ID = "camera_aligned_depth_to_color_frame";
const std::string DEFAULT_ALIGNED_DEPTH_TO_INFRA1_FRAME_ID = "camera_aligned_depth_to_infra1_frame";
const std::string DEFAULT_ALIGNED_DEPTH_TO_INFRA2_FRAME_ID = "camera_aligned_depth_to_infra2_frame";
const std::string DEFAULT_ALIGNED_DEPTH_TO_FISHEYE_FRAME_ID = "camera_aligned_depth_to_fisheye_frame";

const std::string DEFAULT_UNITE_IMU_METHOD = "";
const std::string DEFAULT_FILTERS = "";
const std::string DEFAULT_TOPIC_ODOM_IN = "";
const std::string DEFAULT_D2C_MODE = "sw";  // sw = software mode, hw = hardware mode
const float ROS_DEPTH_SCALE = 0.001;
const int TIME_FILTER_LENGTH = 10;

// Product IDs (PIDs) - Critical for Device Recognition
// Astra Series
constexpr static uint32_t ASTRA_PRO_PID = 0x0601;       // Standard Astra Pro
constexpr static uint32_t ASTRA_PRO_PLUS_PID = 0x0602;  // Astra Pro Plus
constexpr static uint32_t ASTRA_PRO_UVC_PID = 0x0501;   // UVC Color Stream

// Dabai Series
constexpr static uint32_t DABAI_DCW_RGB_PID = 0x0559;
constexpr static uint32_t DABAI_PRO_PID = 0x0655;
constexpr static uint32_t DABAI_MINI_PID = 0x0656;
constexpr static uint32_t DABAI_DC1_PID = 0x0657;
constexpr static uint32_t DABAI_D1_PID = 0x0658;
constexpr static uint32_t DABAI_DCW_DEPTH_PID = 0x0659;
constexpr static uint32_t DABAI_DW_PID = 0x065a;
constexpr static uint32_t DEEYEA_PID = 0x050b;
constexpr static uint32_t ASTRA_DABAI_DEPTH_PID = 0x060e;
constexpr static uint32_t ASTRA_DABAI_UVC_PID = 0x050e;
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

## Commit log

2025-12-27 First commit: Initial robot setup and mapping
    [Tof_BL_link.STL, Tof_BR_link.STL, Tof_FL_link.STL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]
2026-01-09 Initial commit of AMR project: Camera, LiDAR, and Micro-ROS modules
2026-01-20 Initial commit: AMR project with LiDAR, ESP32, and EKF configuration
    [amr_robot.SLDASM.csv, amr_robot.SLDASM.urdf]
2026-01-21 Initial commit - robot motor and odom code
    [amr_robot.csv, amr_robot.urdf]
2026-01-24 DO nav2 for AMR Robot project
    [Tof_BL_link.STL, Tof_BR_link.STL, Tof_FL_link.STL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]
